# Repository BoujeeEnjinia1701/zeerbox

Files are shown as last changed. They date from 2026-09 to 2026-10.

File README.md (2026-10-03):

# ZeerBox

     

**Area:** Agriculture · **TRL:** 3 of 9 (proof of concept on paper) · **Prototype budget:** $300 USD for the cooling equipment kit · **Difficulty:** 2 of 5

Walk-in evaporative cooling chamber with a solar fan that forces air through a wetted pad, and a controller that responds to humidity.

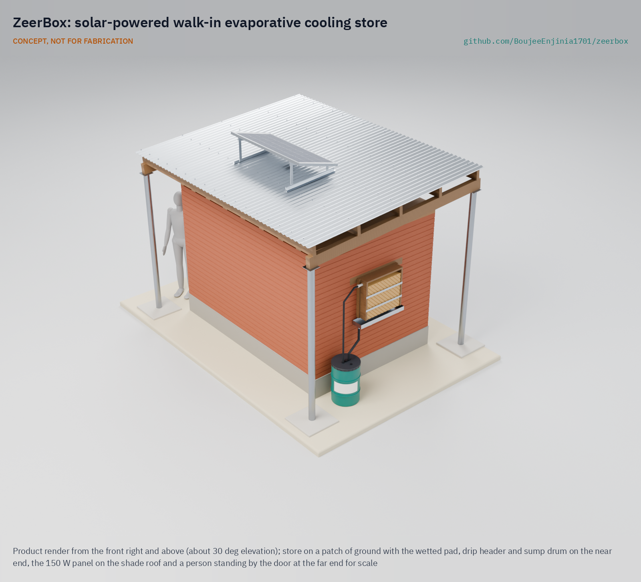
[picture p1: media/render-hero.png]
ZeerBox: solar-powered walk-in evaporative cooling store, product render


[Exploded render](media/render-exploded.png) · [Detail render](media/render-detail.png) · [Interactive 3D model](media/viewer.html) · [Concept blueprint (PDF)](media/concept-blueprint.pdf) · [General arrangement ZBX-DWG-001 (PDF)](cad/drawings/ZBX-DWG-001.pdf) · [Sizing note ZBX-CAL-001](docs/04-calcs/01-sizing.md) · [Prototype build plan](docs/05-build-plan.md) · [Design decisions](docs/06-design-decisions.md) · [Review note](docs/REVIEW.md)

## Concept rationale

Refrigeration is the right answer for a market hub with a business behind it, but it is the wrong starting point for a farm with no grid and no capital. Evaporative cooling needs only water, air and a little power, and in hot, dry weather it can hold produce several kelvin below the outside air (about 10 K on paper for ZeerBox). ZeerBox takes the principle of the clay zeer and the brick zero energy cool chamber and scales it to a room a person can walk into, with shelves at working height, a pad and two 12 V fans for a controlled airflow, and a controller that stops the store from making things worse when the air turns humid.

It is open and garage-buildable because the people who need it are far from any supplier of cold rooms. The structure is ordinary masonry, timber and corrugated sheet that a local mason and carpenter already know, and the cooling kit is a poultry-house pad, generic DC fans, a small pump and solar home system parts, all replaceable from a regional town. Publishing the geometry, calculations and bill of materials lets a partner adapt the size, wall material and crop mix to its own site.

## Burning platform

About 14 % of the food produced for human consumption is lost between harvest and retail, and a further 17 % is wasted. UNEP and FAO estimate that the lack of effective refrigeration alone caused the loss of 12 % of total food production in 2017, enough to feed around 1 billion people at a time when 811 million were hungry ([UNEP and FAO, *Sustainable Food Cold Chains*, 2022](https://www.unep.org/resources/report/sustainable-food-cold-chains-opportunities-challenges-and-way-forward)).

The losses fall hardest on perishables and on the farmers who grow them. Without a cool place to hold a harvest for a few days, a grower must sell on the day of picking at whatever price is offered. A solar walk-in cold room in the Malawi and Zimbabwe pilots cost about $40,000 per unit ([Efficiency for Access](https://efficiencyforaccess.org/wp-content/uploads/Lessons-learned-from-implementing-solar-powered-walk-in-cold-rooms-for-smallholder-agriculture-in-Zimbabwe-and-Mal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)), far beyond a smallholder or a small farmer group.

## Where it could be used

### By industry

| Industry | Use |
| --- | --- |
| Smallholder horticulture | Hold one to five days of tomatoes, peppers, okra and leafy greens so they can be sold when the price is right |
| Farmer groups and cooperatives | Shared store at a collection point, loaded by several members on a rota |
| Market trading | Keep stock fresh between market days at a stall or small depot |
| Agricultural extension and NGOs | Demonstration store and training unit for postharvest handling programs |
| School and community gardens | Short-term storage of garden produce for school meals or local sale |

### By country or region

| Country or region | Why it matters there |
| --- | --- |
| Mali and the wider Sahel | Long hot, dry seasons suit evaporative cooling; in field use in Mali, brick chambers cut the daily peak temperature by up to 10.4 °C when the air was below 40 % RH, but by only 4.2 °C above 70 % RH ([Verploegen, Sanogo and Chagomoka, MIT D-Lab](https://d-lab.mit.edu/sites/default/files/inline-files/GHTC%20-%20Evaluation%20of%20Low-Cost%20Evaporative%20Cooling%20Technologies%20for%20Improved%20Vegetable%20St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); [MIT News, 2018](https://news.mit.edu/2018/mit-d-lab-cite-evaluation-low-cost-evaporative-cooling-devices-mali-0620)) |
| Northern Nigeria | Home of the modern zeer revival ([*TIME*, 2001](https://content.time.com/time/specials/packages/article/0,28804,1936165_1936254_1936632,00.html)); pay-per-crate solar walk-in cold rooms such as ColdHubs, at about $0.50 per crate per day, sit in markets, collection centers and farm clusters rather than on individual farms ([ColdHubs](https://coldhubs.com/); [IFPRI](https://www.ifpri.org/blog/coldhubs-addressing-crucial-problem-food-loss-nigeria-solar-powered-refrigeration/)) |
| India | The zero energy cool chamber was developed at the Indian Agricultural Research Institute; one study found tomato shelf life rising from 6 to 11 days ([*e-planet* 18(2)](https://www.e-planet.co.in/images/Publication/vol-18-2/storage.pdf)) |
| Kenya | MIT D-Lab has piloted forced-air evaporative chambers, some solar powered, the closest prior work to ZeerBox ([MIT D-Lab](https://d-lab.mit.edu/research/evaporative-cooling-vegetable-preservation)) |
| Malawi and Zimbabwe | Solar cold room pilots showed the demand and the cost, about $40,000 per unit, with some rooms largely unused ([Efficiency for Access](https://efficiencyforaccess.org/wp-content/uploads/Lessons-learned-from-implementing-solar-powered-walk-in-cold-rooms-for-smallholder-agriculture-in-Zimbabwe-and-Mal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)) |
| Australia (arid interior) | A high-income example with a long evaporative tradition: the Coolgardie safe, invented in the Western Australian goldfields in the late 1890s, kept food cool by trickling water through a hessian cover ([Western Australian Museum](https://visitwanderland.com.au/explore/golden-outback/warden-finnertys-residence/coolgardie-safe)) |

## What sparked the idea

The idea traces back to the pot-in-pot cooler, or zeer, that Mohammed Bah Abba popularized in Nigeria from 1995: a small earthenware pot inside a larger one, with moist sand between them, cooling the inner pot as the water evaporates ([MIT D-Lab, evaluation of evaporative cooling in Mali](https://d-lab.mit.edu/sites/default/files/inline-files/GHTC%20-%20Evaluation%20of%20Low-Cost%20Evaporative%20Cooling%20Technologies%20for%20Improved%20Vegetable%20St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)). Bah Abba, a teacher from a potmaking family, received a Rolex Award for Enterprise for the work; *TIME* reported that eggplants kept for 27 days instead of three and that 12,000 coolers had been sold ([*TIME*, Best Inventions of 2001](https://content.time.com/time/specials/packages/article/0,28804,1936165_1936254_1936632,00.html)). The zeer shows how far evaporation can go with no power at all, and also where it stops: a pot holds a family's vegetables, not a farmer's harvest, and it cannot tell when the air is too humid to cool. ZeerBox keeps the principle and the name and asks what the same idea looks like at the scale of a walk-in room, with a fan, a deeper pad and a sensor to decide when to use them.

## Problem

Smallholders lose produce after harvest because they have no cold storage. Refrigerated cold rooms cost tens of thousands of dollars, and passive evaporative coolers are small and fail in humid weather. Design with, not for: requirements must come from co-design sessions and field trials with the intended users through a local partner.

## Concept

A walk-in store (2.4 x 1.5 x 2.0 m inside, 24 crates) with double brick walls around a dry rice husk cavity. Two 12 V fans pull outside air through a 150 mm wetted cellulose pad, and a controller reads temperature and humidity inside and out to choose between evaporative cooling, night ventilation and hold. A 150 W solar panel with a small battery powers it. The TRL 3 calculation puts the store at about 24.3 °C on a 35 °C, 30 % RH day, 10.7 K below the outside air, using about 36 L of water. Store humidity is about 81 %, just above the 80 % target and at risk in the unfavorable case (estimates, [ZBX-CAL-001](docs/04-calcs/01-sizing.md)).

Full design precis: [docs/02-concept.md](docs/02-concept.md)

## Key components

- Double brick walls with a dry rice husk cavity, insulated ceiling and shade roof
- 150 mm cellulose evaporative pad with drip header and gutter
- Two 250 mm 12 V DC exhaust fans in a ceiling fan box at the door end
- 60 L sump drum with a 12 V pump
- 150 W PV panel, 20 A PWM charge controller and small LiFePO4 battery
- Controller with inside and outside humidity and temperature sensors

The priced bill of materials is in [bom/bom.csv](bom/bom.csv). Value-engineering target: USD 300 for the cooling equipment kit. Estimated cost of the constructable design: USD 299 for the kit (USD 1 under the target); the structure is built from local materials and costed separately, about USD 574 (indicative).

## Building the prototype

The prototype build plan ([ZBX-BLD-001](docs/05-build-plan.md)) shows how to build the first store, component by component and step by step, with a making sketch for each of the 18 made components and a picture for every one of the 26 assembly steps. Making the concept buildable added a strip footing, lintels and lined openings, a framed ceiling and roof, and moved the two fans from the front wall into a ceiling fan box (decision record ZBX-DDR-003, accepted by Amish on 2026-10-02). A local mason and carpenter can build it; the cooling kit is bought and fitted. The decisions, all made as of 2026-10-02, are kept in the [design decisions register](docs/06-design-decisions.md).

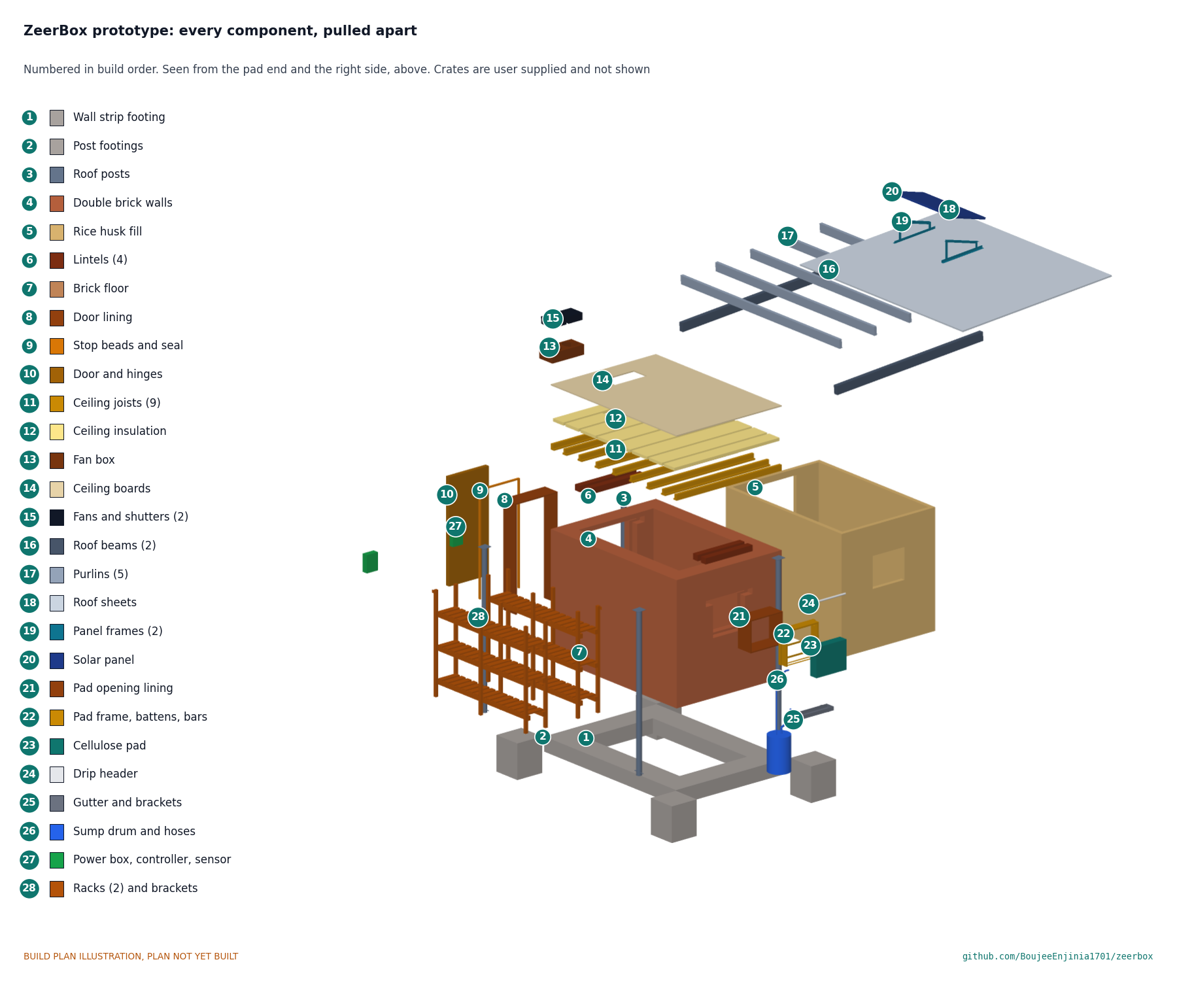
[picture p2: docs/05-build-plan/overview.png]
ZeerBox prototype: every component pulled apart, numbered in build order


## Safety

> A walk-in room: the door must open from inside. Warm recirculating water can grow *Legionella*, so cover, drain and clean the sump weekly. Contains a LiFePO4 battery; use a BMS, fuse it and keep it shaded. Guard the fans. Not for meat, fish, milk or medicines.

## Repository layout

| Folder | Contents |
| --- | --- |
| `docs/` | Problem, concept, requirements, calculations and design decisions |
| `cad/src/` | build123d Python source, the source of truth for all geometry |
| `cad/step/`, `cad/stl/` | Exported models for FreeCAD, other CAD tools and printing |
| `cad/drawings/` | 2D sketches and dimensioned drawings |
| `bom/` | Bill of materials |
| `electronics/` | KiCad schematics and PCB layouts |
| `firmware/` | Microcontroller code |
| `media/` | Renders, perspectives and photos |
| `build-log/` | Dated prototyping notes |

## Documentation

Controlled documents follow the portfolio [documentation standard](.kit/STANDARDS.md). Each carries a document ID (ZBX-PRC-001 for the precis), a version and a revision history. Branded PDFs are built with `python .kit/render.py` and attached to GitHub Releases when a document is tagged, for example `ZBX-PRC-001/v1.0`.

## Credits

Designed by Amish Chadha. See [CONTRIBUTORS.md](CONTRIBUTORS.md) for roles. To cite this design, use [CITATION.cff](CITATION.cff) (GitHub shows it as "Cite this repository").

AI assistance (Claude) was used to accelerate concept renders, prototype documentation and first-pass sizing calculations. Design direction and all decisions are Amish Chadha's, recorded in this repository's decision records (`docs/decisions/`).

## Licenses

- **Hardware** (CAD, drawings, BOM, electronics): [CERN-OHL-S v2](LICENSE)
- **Software** (firmware, scripts, notebooks): [MIT](LICENSE-SOFTWARE)

A project of the [Design Molecule](https://designmolecule.com) lab.

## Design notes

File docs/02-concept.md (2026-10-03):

---
doc_id: ZBX-PRC-001
title: ZeerBox design precis
project: ZeerBox
doc_type: Design precis
version: "0.7"
status: Draft
date: '2026-10-02'
author: Amish Chadha
license: CERN-OHL-S-2.0
revisions:
- version: "0.1"
  date: '2026-09-24'
  author: Amish Chadha
  change: Initial scaffold
- version: "0.2"
  date: '2026-09-25'
  author: Amish Chadha
  change: Populate to TRL 2 (architecture, control modes, first-order numbers, cost, safety, media)
- version: "0.3"
  date: '2026-09-25'
  author: Amish Chadha
  change: TRL 3; record the decisions in ZBX-DDR-001, replace the estimates with ZBX-CAL-001 figures (airflow, heat load, humidity, water, energy, cost), 150 W panel and 20 A charge controller, parametric model and drawing ZBX-DWG-001
- version: "0.4"
  date: '2026-09-25'
  author: Amish Chadha
  change: Recommendations accepted by Amish (DDR-002). 150 mm pad, dry rice husk cavity fill, R3 at 80 % with covered or lined crates; figures from ZBX-CAL-001 v0.2; drawing ZBX-DWG-001 Rev P2
- version: "0.5"
  date: '2026-10-02'
  author: Amish Chadha
  change: "Design made constructable (ZBX-DDR-003): fans in a ceiling fan box, footings, lintels, linings, framed ceiling and roof; cost against the value-engineering target; build plan ZBX-BLD-001 and register ZBX-DEC-001; drawing Rev P3"
- version: "0.6"
  date: '2026-10-02'
  author: Amish Chadha
  change: Design for construction, wall material and partner recorded from Amish's decisions of 2026-10-02 (ZBX-DEC-001)
- version: "0.7"
  date: '2026-10-02'
  author: Amish Chadha
  change: Controller parts list names the clear-lid box, mode lamp position and plate shield (ZBX-DEC-001, decisions 6 to 8)
---

# ZeerBox design precis

ZeerBox is a walk-in store, 2.4 x 1.5 x 2.0 m inside, with double brick walls around a dry rice husk cavity, a shade roof, a 150 mm cellulose pad in the back wall, and two 12 V exhaust fans in the ceiling at the door end that pull outside air through the pad and along the aisle between two shelving racks. A controller reads temperature and humidity inside and outside and chooses between evaporative cooling, night ventilation and hold, and a 150 W solar panel with a small LiFePO4 battery powers it all. The TRL 3 calculation (ZBX-CAL-001 v0.3) shows that on a 35 °C, 30 % RH day the store holds 480 kg of produce at about 24.3 °C, 10.7 K below the outside air, using about 36 L of water and 372 Wh of solar energy. Store humidity is about 81 %, just above the 80 % target (R3, at risk in the unfavorable case). Value-engineering target: USD 300 for the cooling equipment kit. Estimated cost of the constructable design: USD 299 for the kit (USD 1 under the target); the structure, about USD 574 in local materials, is costed separately. How to build it is in the prototype build plan ([ZBX-BLD-001](05-build-plan.md)).

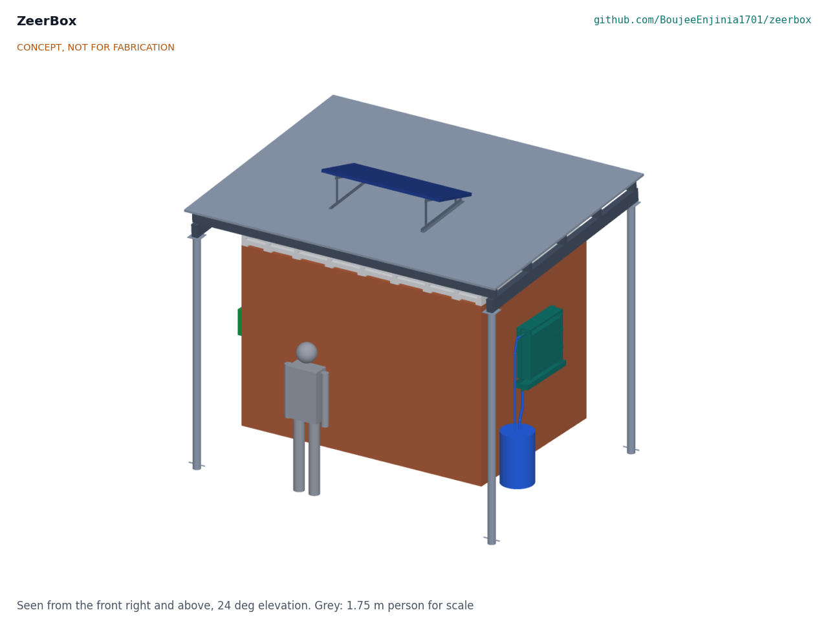
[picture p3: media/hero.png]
Hero render


*Figure 1. ZeerBox from the TRL 3 parametric model, with the pad and sump on the back wall, the 150 W panel on the shade roof and a 1.75 m person for scale. The door is on the far end, with the fan box in the ceiling above it.*

## How it works

1. **Wet.** A 12 V pump in a 60 L sump drum lifts about 3.6 L/min to a perforated header on top of the pad. Water runs down through the 150 mm cellulose pad and drains back to the sump through a gutter. The wall cavity is filled with dry rice husk, which insulates the store and needs no water.
2. **Cool.** Two 250 mm fans in a plywood fan box in the ceiling at the door end exhaust air from the store up into the shaded roof space, which pulls outside air in through the wetted pad on the opposite wall. At the fan and pad operating point of about 563 m³/h, evaporation cools the air from 35 °C toward its wet-bulb temperature of 21.5 °C; with a pad effectiveness of about 88 %, it enters at 23.1 °C and 87 % RH.
3. **Store.** Air sweeps along the 0.6 m aisle and across 24 crates on two three-level timber racks, picking up about 440 W from the walls, ceiling, floor, produce and the day's warm field produce, and leaves through the fans at about 25.5 °C. Leafy and water-sensitive produce goes in covered or lined crates, which hold humidity near the produce.
4. **Decide.** A controller compares the inside and outside readings every minute and runs one of four modes (below). A three-color lamp by the door shows the mode, so users know when to keep the door shut and when the store is not cooling.
5. **Power.** A 150 W panel on the shade roof charges a 12.8 V, 12 Ah LiFePO4 battery through a 20 A PWM charge controller. The battery covers cloud and about 2 h of evening ventilation.

The shade roof sits 450 mm above an insulated ceiling so that sun never falls on the storage room, and its overhang shades the walls for most of the day.

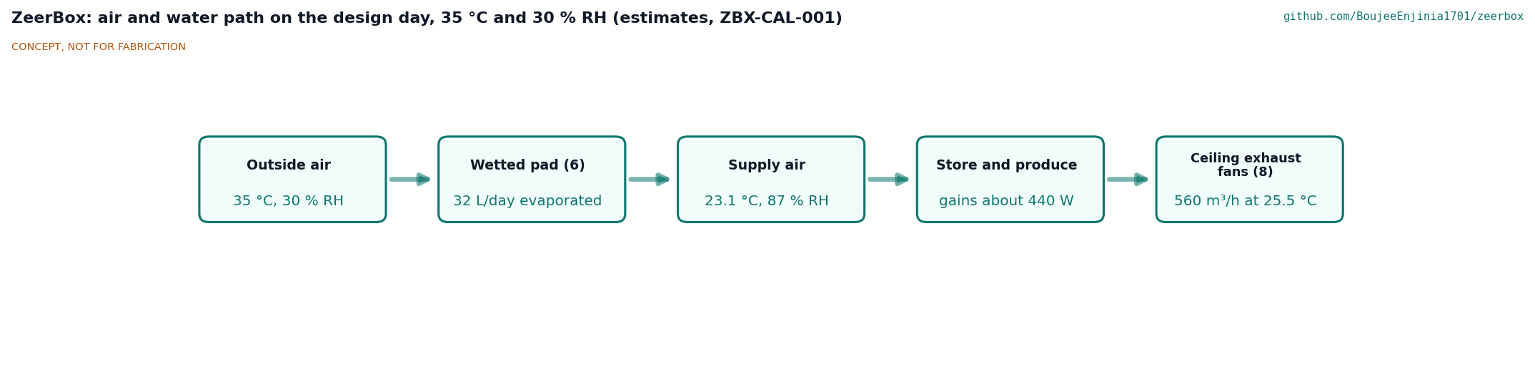
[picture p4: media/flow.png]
Air and water path


*Figure 2. Air and water path on the design day, 35 °C and 30 % RH. Values from ZBX-CAL-001; all are estimates.*

### Control modes

The thresholds are starting values for field tuning (decided by Amish, 2026-09-25, ZBX-DDR-001 item 8).

| Mode | When | Fans | Pump | Lamp |
| --- | --- | --- | --- | --- |
| Evaporative cooling | Outside wet-bulb depression 4 K or more and store above its 20 °C set point | On, speed by store temperature | On, duty cycled to keep the pad wet | Green |
| Night ventilation | Outside air at least 2 K cooler than the store, whatever its humidity | On, at reduced speed after the 2 h evening run | Off | Blue |
| Hold | Outside warmer than the store and too humid to cool | One fan at about 30 % speed, about 8 air changes an hour | Off | Amber |
| Guard | Store RH above 95 % for 60 min, sump float low, or battery low | Low | Off | Red, flashing |

The battery can carry full-speed night ventilation for only about 2.5 h beyond the evening run (ZBX-CAL-001 section 7), so night ventilation runs at reduced speed. The controller logs both sensor pairs and the mode every 10 min to a memory card, so a partner can compare seasons and sites. Firmware is out of scope at TRL 3 beyond a labeled sketch of this logic.

## Main components

Numbers match the exploded view (Figure 3) and `bom/bom.csv`. Dimensions come from `cad/src/model.py` and drawing ZBX-DWG-001.

| # | Component | Choice | Notes |
| --- | --- | --- | --- |
| 1 | Double brick walls and floor | Two 115 mm fired-brick leaves around a 75 mm cavity, 305 mm total, outside 3,010 x 2,110 mm; brick floor on compacted sand; about 1,980 bricks | Fired brick, decided by Amish 2026-10-02 (ZBX-DEC-001) |
| 2 | Dry rice husk cavity fill | About 1.3 m³ of dry rice husk mixed with hydrated lime, on a damp-proof course, capped with mortar | Decided (ZBX-DDR-002 item 12); dry sand is the fallback |
| 3 | Insulated ceiling | Timber boards with about 50 mm of straw, rice husk or foam and a plastic vapor sheet | Keeps roof heat out |
| 4 | Shade roof on posts | Corrugated steel, 3.9 x 3.0 m, on four 90 mm posts in 500 x 500 x 600 mm concrete footings, 450 mm clear above the ceiling | Carries the solar panel; 500 mm footings kept as a minimum (ZBX-DDR-002 item 13) |
| 5 | Insulated door with seal | 0.8 x 1.8 m, timber frame, plywood skins, 50 mm insulation, rubber seal, inside release | Opens from inside without a key |
| 6 | Cellulose pad, frame, header and gutter | 150 mm pad, 0.6 x 0.5 m (0.3 m²), center 1.25 m above ground, with a drip header and return gutter | Decided (ZBX-DDR-002 item 11; was 100 mm) |
| 7 | Sump drum, pump and hoses | 60 L covered drum, 12 V submersible pump about 6 W at 2 m head, float switch, feed and return hoses | Drained and cleaned weekly |
| 8 | Exhaust fans (pair) | Two 250 mm 12 V DC axial fans with guards and gravity shutters, in a ceiling fan box at the door end, blowing up into the roof space (ZBX-DDR-003) | About 12 W and about 280 m³/h each in service |
| 9 | Controller and sensors | Low-cost microcontroller, two digital temperature and RH sensors (inside, outside in a six-plate shield), MOSFET drivers, memory card, mode lamp on top of the box, clear-lid IP65 box | Generic parts |
| 10 | Solar panel | 150 W monocrystalline, about 1,480 x 670 mm, on the shade roof | Decided (item 2) |
| 11 | Power box | 20 A PWM charge controller, 12.8 V 12 Ah LiFePO4 battery with BMS, 15 A fuse, in a ventilated box | Battery decided (item 3); outside the store, shaded |
| 12 | Shelving racks | Two timber racks, 2.2 m long and 0.45 m deep, shelves at 0.30, 0.85 and 1.40 m above the floor | Termite-treated timber or steel angle |
| 13 | Produce crates | 24 ventilated crates, about 500 x 350 x 300 mm, 20 kg each | User supplied; not in the cost |

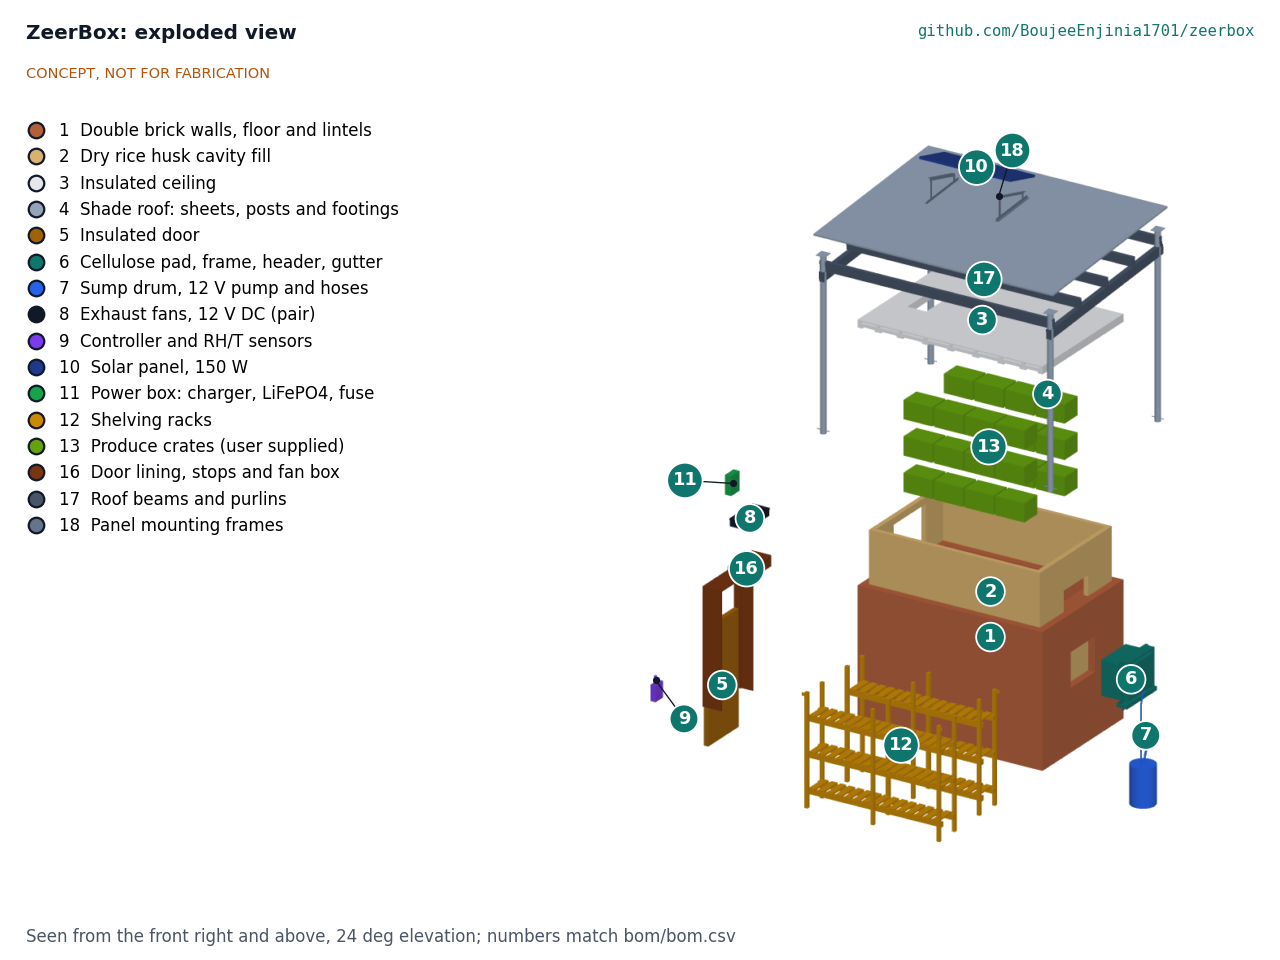
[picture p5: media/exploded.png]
Exploded view


*Figure 3. Exploded view with numbered callouts matching the BOM. The racks are drawn out in front; the crates, ceiling, roof and panel are lifted.*

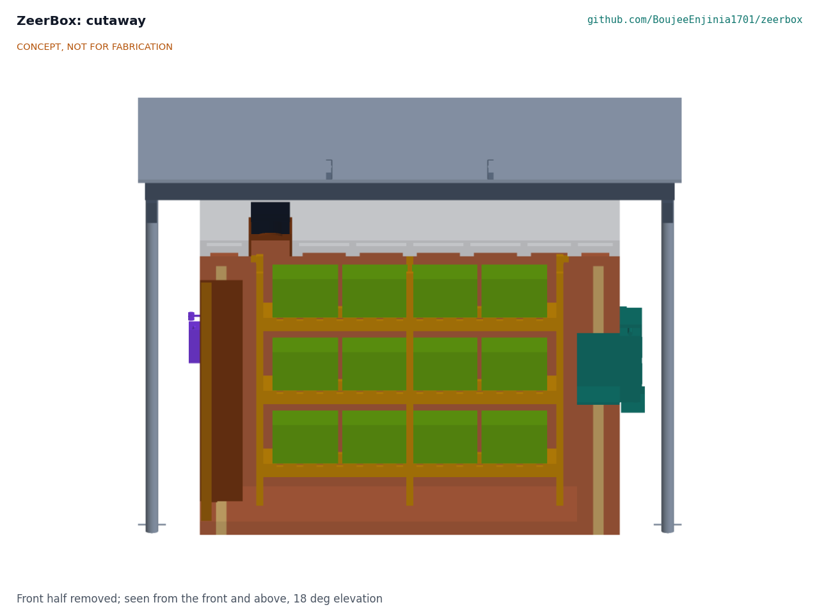
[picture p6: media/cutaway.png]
Cutaway


*Figure 4. Section along the aisle, looking at one rack. The door and the ceiling fan box are at left, the pad at right, and the dry rice husk cavity shows as the pale band inside each end wall.*

## TRL 3 figures

All values come from ZBX-CAL-001 v0.3 (`python docs/04-calcs/sizing.py`). They are first-principles estimates, not measurements. The central case is quoted with the favorable to unfavorable range where it matters.

### Air, pad and store temperature

*Table 1. Design point, 35 °C and 30 % RH.*

| Quantity | Value | Basis |
| --- | --- | --- |
| Outside wet-bulb temperature | 21.5 °C | ASHRAE psychrometric relations |
| Airflow at the fan and pad operating point | 563 m³/h (331 cfm), 18 Pa; about 78 air changes an hour | Two fans on a straight-line curve against the 150 mm pad, shutters and guards |
| Pad face velocity and effectiveness | 0.52 m/s, about 88 % | NTU model calibrated to 75 % at 0.6 m/s for 100 mm, scaled to 150 mm |
| Supply air after the pad | 23.1 °C, 87 % RH | |
| Heat load | 442 W (376 to 558 W) | Walls, ceiling, floor, door, respiration, field heat, leaks |
| Exhaust air | 25.5 °C, 77 % RH | Supply plus 2.35 K |
| Mean store air | 24.3 °C, 81 % RH | |
| **Temperature drop below ambient** | **10.7 K (9.8 to 11.4 K)** | R2 (8 K) met in every case |

This matches field experience: D-Lab measured more than 8 °C of cooling from brick chambers in Mali's dry season. It also shows the limit. The store runs at about 24 °C, well above the 12.5 to 15 °C that tomatoes prefer, so ZeerBox slows spoilage rather than stopping it.

### Humidity

The store averages about 81 % RH while cooling (77 to 85 %), against 80 % in R3, relaxed from 85 % by ZBX-DDR-002. The supply air leaves the 150 mm pad at 87 % RH and loses about 4 to 5 percentage points of RH for every kelvin it warms in the store, so R3 is at risk in the unfavorable case. Reaching 85 % would need a pad about 185 mm deep or more. Covered or lined crates for leafy and water-sensitive produce hold humidity near the produce; they are an operating practice, not a kit item.

### Walls

The decided dry rice husk fill lets in about 84 W through the walls with no water. With the 150 mm pad, a wet sand cavity would let in about 163 W and use about 12 L of water a day, and dry sand (the fallback if no durable, pest-proof husk supply exists) about 192 W. The husk sits on a damp-proof course, is mixed with hydrated lime against insects and is capped with mortar, so it stays dry and closed to rodents.

### Water

| Quantity | Value | Requirement |
| --- | --- | --- |
| Evaporated at the pad | 32 L/day (29 to 35 L) | |
| Wall cavity | none (dry fill) | |
| Bleed, splash and cleaning | 4 L/day | |
| **Total** | **about 36 L/day** | R8 (70 L) met; the 60 L sump covers the 36 L of pad and bleed water |

### Energy

| Quantity | Value | Requirement |
| --- | --- | --- |
| Load while cooling | 31 W (fans 24 W, pump 6 W, controller 1 W) | |
| Daily energy | 372 Wh (fans 288, pump 60, controller 24) | |
| Panel yield, 150 W | 525 Wh/day at 5 peak sun hours and 30 % losses | R7 met, 41 % margin |
| Battery | 154 Wh, 123 Wh usable; 62 Wh needed after sunset | |
| Charge controller | 20 A PWM (1.25 x 9 A Isc) | 10 A was too small |

### Humid weather

| Outside air | Wet-bulb depression | Supply air | Mean store | Drop | Mode |
| --- | --- | --- | --- | --- | --- |
| 35 °C, 30 % RH (design point) | 13.5 K | 23.1 °C | 24.3 °C | 10.7 K | Evaporative cooling |
| 38 °C, 15 % RH | 18.8 K | 21.4 °C | 22.8 °C | 15.2 K | Evaporative cooling |
| 32 °C, 50 % RH | 8.3 K | 24.6 °C | 25.6 °C | 6.4 K | Evaporative cooling |
| 30 °C, 75 % RH | 3.7 K | 26.7 °C | 27.5 °C | 2.5 K | Hold by day, night ventilation |

In the rainy season ZeerBox does little more than a shaded, ventilated shed. The controller's job then is to avoid making things worse: no wet pad adding humidity to a damp room, and cool night air let in whenever it is available.

### Cost

| Group | Indicative cost | Requirement |
| --- | --- | --- |
| Cooling equipment kit (items 6 to 11, 14 and 18) | about $299 | R12: USD 1 under the USD 300 value-engineering target |
| Structure (items 1 to 5, 12, 15, 16 and 17), materials only, costed separately | about $574 | |
| Store total, crates excluded | about $873 | |
| Crates (item 13, user supplied) | about $96 if bought | Not in the total |

Labor for the mason and carpenter is not included.

## Key design choices

Items marked "decided" were decided by Amish on 2026-09-25 (go with recommendation, ZBX-DDR-001 and ZBX-DDR-002) or on 2026-10-02 (ZBX-DEC-001).

- **Forced air through a pad, not a passive chamber (decided).** A fan and pad give a larger, walk-in store with shelves at working height and a controlled airflow; a passive ZECC is cheaper and needs no power but holds far less and cannot respond to humidity.
- **Exhaust fans, pad on the opposite wall (decided).** Pulling air through the pad spreads it evenly over the pad face and keeps the fan motors out of the humid supply air.
- **Dry rice husk cavity fill (decided).** Replaces the wet sand cavity borrowed from the ZECC, which ZBX-CAL-001 found worth little. Decided by Amish, 2026-09-25: go with recommendation (ZBX-DDR-002 item 12), subject to a durable, pest-proof husk supply locally; dry sand is the fallback.
- **Size (decided).** 2.4 x 1.5 x 2.0 m inside for 24 crates, kept until the partner confirms the need.
- **Panel size (decided).** 150 W, with a 20 A charge controller.
- **Battery (decided).** A small LiFePO4 battery for evening ventilation and cloud.
- **Set point and thresholds (decided).** 20 °C set point, 4 K wet-bulb depression threshold and 95 % RH guard as starting values for field tuning.
- **Budget (decided).** `budget_usd: 300` covers the cooling equipment kit; the structure is costed separately. Since 2026-10-01 it is a hypothetical value-engineering target, not a limit.
- **Design for construction (accepted by Amish, 2026-10-02).** Footings, lintels, linings, a framed ceiling and roof, and the fans moved from the front wall to a ceiling fan box, so that every part can be built (ZBX-DDR-003). Decisions are recorded in the register ZBX-DEC-001.
- **Wall material (decided).** Fired brick, as modelled and calculated: the pad wall is kept wet and fired brick does not soften (decided by Amish, 2026-10-02, ZBX-DEC-001).
- **Pad depth and R3 (decided).** A 150 mm pad, R3 relaxed to 80 %, and covered or lined crates for sensitive produce (ZBX-DDR-002 item 11).
- **Roof footings (decided).** 500 x 500 x 600 mm footings as a minimum; the local design wind speed is confirmed with a builder at the chosen site (ZBX-DDR-002 item 13).

## Safety

> **Safety:** ZeerBox is a walk-in room that people enter, with a lithium iron phosphate battery, spinning fans, standing warm water, heavy masonry and a roof that can catch the wind. Treat each of these as a hazard at every stage.

- **Entrapment and air quality.** The door must open from inside at all times, with no outside lock that can be closed on a person inside. Produce respires and uses oxygen; with the fans off and door shut for a long time, open the door and let the store air out before entering.
- **Water-borne bacteria.** Warm recirculating water in pads and sumps can grow *Legionella* and other bacteria, and the fine droplets from a pad can carry them. Cover the sump, drain and clean it weekly, dry the pad out regularly, never use the sump water for drinking or washing produce, and replace a pad that smells or grows slime. Covered water also stops mosquitoes breeding.
- **Mold and spoilage.** A damp, poorly ventilated store can spread mold between crates. The guard mode, weekly cleaning and removal of rotten produce are part of operation.
- **Battery.** A 154 Wh LiFePO4 battery is far less prone to thermal runaway than other lithium chemistries but can still overheat or short. Use a battery with a BMS rated for at least 10 A of charge, fuse it at the terminal, keep it shaded and ventilated outside the store, and do not charge it below 0 °C or above 45 °C.
- **Electrical.** All wiring is 12 V DC and below the touch-safety threshold, but water and wiring meet at the pad and pump. Use IP65 connections, drip loops and a fused supply. Size the charge controller for 1.25 times the panel's short-circuit current.
- **Moving parts.** Fans need guards on both faces. Isolate power before cleaning a fan or the pump.
- **Structure.** Masonry walls (about 7 t of brick) and a roof that people stand under must be built by a competent mason. At a 30 m/s gust each roof post sees about 1.9 kN of uplift after the roof's own weight; set the posts in footings of at least 500 x 500 x 600 mm with an anchor bar through each post foot, tie every purlin to its beam, screw the sheets down, confirm the local design wind speed, and inspect for cracks each season.
- **Rice husk fill.** Dry husk is combustible. Keep the cavity capped with mortar, keep flames and hot work away from the walls during building, and keep the solar wiring in conduit where it passes the wall top.
- **Food safety.** Cooling slows spoilage; it does not make produce safe to eat. ZeerBox is not for meat, fish, milk or medicines.

## Open questions

- Confirm a durable, pest-proof rice husk supply near the chosen site, or fall back to dry sand (ZBX-DDR-002 item 12).
- Confirm the local design wind speed with a builder (ZBX-DDR-002 item 13).
- Confirm pad effectiveness and pressure drop, and the fan curve, from supplier data for the chosen parts.
- Review MIT D-Lab's forced-air evaporative chamber work in Kenya in detail and contact the team.
- Approach the first candidate partner, MIT D-Lab's evaporative cooling team, for a site in Mali's dry-season vegetable areas (decided by Amish, 2026-10-02, ZBX-DEC-001).
- The decisions and the items to confirm are kept in the design decisions register, ZBX-DEC-001 ([docs/06-design-decisions.md](06-design-decisions.md)).

Concept media: [blueprint sheet](../media/concept-blueprint.pdf), [interactive 3D model](../media/viewer.html). General arrangement: `cad/drawings/ZBX-DWG-001.pdf`.

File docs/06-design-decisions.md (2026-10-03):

---
doc_id: ZBX-DEC-001
title: ZeerBox design decisions register
project: ZeerBox
doc_type: Design decisions register
version: "0.2"
status: Draft
date: '2026-10-02'
author: Amish Chadha
license: CERN-OHL-S-2.0
revisions:
  - version: "0.1"
    date: '2026-10-02'
    author: Amish Chadha
    change: Register opened with the build plan; budget treated as a value-engineering target
  - version: "0.2"
    date: '2026-10-02'
    author: Amish Chadha
    change: Amish approved the recommendations for open items 1 to 10 on 2026-10-02 (ZBX-DDR-003 accepted with A1 and A2, fired brick, MIT D-Lab and Mali as first candidates, appearance items); moved to decisions made
---

# ZeerBox design decisions register

Every design decision still to be made, and every decision made, in one place. Each decision is argued in full in its decision record under `docs/decisions/` or in the review note; this register is the index Amish works from. The build plan (`docs/05-build-plan.md`) describes the design as it stands and does not list open decisions.

## Open decisions

None. All open decisions were decided on 2026-10-02.

## To confirm when parts are bought

| # | What to confirm | Why it matters | Source |
| --- | --- | --- | --- |
| 1 | The fan frame is no wider than 290 mm and fits a 250 mm hole | The fan box bay is 310 mm between joists | ZBX-DDR-003, C1 |
| 2 | The fan curve and the pad's pressure drop and effectiveness from supplier data | The airflow of about 560 m³/h and the 10.7 K drop rest on assumed curves | ZBX-CAL-001, sections 1 and 3 |
| 3 | The panel frame has mounting holes on its back flange that the top rails can reach | The panel bolts to the mounting frames through them | ZBX-DDR-003, C8 |
| 4 | Hurricane ties are rated 2 kN or more in uplift | Each purlin crossing sees about 1.1 kN at a 30 m/s gust | ZBX-CAL-001, Table 6a |
| 5 | A durable, pest-proof rice husk supply near the site; otherwise dry sand | The fill's insulation and the wall heat gain depend on it | ZBX-DDR-002, item 12 |
| 6 | The local design wind speed, confirmed with a builder | The roof footings and ties are sized for a 30 m/s gust | ZBX-DDR-002, item 13 |
| 7 | The pump gives about 3.6 L/min at 2 m head and has a float switch | The pad must stay wet and the pump must not run dry | ZBX-CAL-001, section 8 |
| 8 | The charge controller is set for 12.8 V lithium iron phosphate and the BMS takes 10 A of charge | Battery safety and life | ZBX-CAL-001, section 7 |

## Value engineering

Value-engineering target: USD 300 for the cooling equipment kit (a hypothetical control target, not a limit). Estimated cost of the constructable design: USD 299 for the kit (USD 1 under the target). The structure is costed separately at USD 574, and the whole store at USD 873, crates excluded. Main cost drivers and savings worth trying:

- The largest kit lines are the 150 W panel (USD 62), the power box with its battery (USD 62), the pad with its frame, header and gutter (USD 50), the two fans (USD 30) and the controller (USD 30).
- Making the design constructable added USD 22 for the two panel mounting frames and USD 10 for the pad frame, lining, bars and brackets, less USD 3 for the roof clamps they replace: the kit rose from USD 270 to USD 299.
- The structure rose from USD 355 to USD 574 because the concept did not price the strip footing (USD 35), the roof beams and purlins (USD 70) or the door lining and fan box (USD 25), and underpriced the framed ceiling and the racks.
- Savings worth trying: galvanized steel angle in place of aluminium for the panel frames (about USD 8 less, needs painting at cut ends); a 100 W panel is not one (6 % short on energy, ZBX-CAL-001 section 7); in the structure, mud brick or stabilized block if decision 4 allows, and racks of local poles in place of sawn timber.

## Decisions made

| Date | Decision | Decided by | Record |
| --- | --- | --- | --- |
| 2026-09-25 | TRL 2 review items 1 to 8: the USD 300 budget covers the cooling kit with the structure costed separately; 150 W panel; keep the battery; forced air through a pad; exhaust fans with the pad opposite; wet sand cavity pending the heat balance; 24 crates; control thresholds as starting values | Amish: "proceed with all of your recommendations across all batches. Make sure we don't proceed to TRL 4 on any of them." | ZBX-DDR-001 |
| 2026-09-25 | Items 11 to 13: 150 mm pad, R3 relaxed to 80 % with covered or lined crates; dry rice husk fill in place of wet sand (dry sand as fallback); 500 x 500 x 600 mm roof footings as a minimum | Amish: "i accept all your recommendations, go with them across all repos." | ZBX-DDR-002 |
| 2026-09-30 | Make the design physically buildable while drawing the build plan | Amish: "If you are realising that the design cannot be built as per concept - fix the design assumptions to match and be physically feasible as you draw the illustrations." | ZBX-DDR-003 (the changes themselves await his review, open decision 1) |
| 2026-09-30 | Open decisions are kept in this register, not in the build plan | Amish: "don't log outstanding decisions in this build plan - that is not the place for it. that should be in a separate design document logged and named as such" | This register |
| 2026-10-01 | `budget_usd` is a value-engineering target, not a spending limit | Amish: "the budgets are a hypothethical control target to ensure we are thinking along a value engineering lens. its ok to ensure wording reflects that the hypothesis budget was x - the real cost being accrued is y" | ZBX-CAL-001 v0.3, section 11 |
| 2026-10-02 | Design for construction accepted: the changes C1 to C10 of ZBX-DDR-003, as made | Amish: "APPROVED: The open decisions from the last wave (TremorTrace to ZeerBox) came in after the review and aren't on the page either." | ZBX-DDR-003, Table 1 |
| 2026-10-02 | Fan position: the two fans stay in the ceiling fan box at the door end, as modelled | Amish: "APPROVED: The open decisions from the last wave (TremorTrace to ZeerBox) came in after the review and aren't on the page either." | ZBX-DDR-003, A1 |
| 2026-10-02 | Exhaust into the roof space accepted, with a check at TRL 4 that moist air does not drift back to the pad; a short duct past the roof edge is added only if it does | Amish: "APPROVED: The open decisions from the last wave (TremorTrace to ZeerBox) came in after the review and aren't on the page either." | ZBX-DDR-003, A2 |
| 2026-10-02 | Wall material: fired brick, as modelled and calculated | Amish: "APPROVED: The open decisions from the last wave (TremorTrace to ZeerBox) came in after the review and aren't on the page either." | ZBX-DDR-001, item 9 |
| 2026-10-02 | First co-design partner, region and crop mix: a group that has already field-tested evaporative cooling chambers with vegetable growers; the first candidate to approach is MIT D-Lab's evaporative cooling team, with a dry-season vegetable area of Mali as the first candidate region and tomatoes, peppers and okra as the crop mix, leafy greens on a separate rack | Amish: "APPROVED: The open decisions from the last wave (TremorTrace to ZeerBox) came in after the review and aren't on the page either." | ZBX-DDR-001, item 10 |
| 2026-10-02 | Clear window in the controller lid only; the power box has a plain door | Amish: "APPROVED: The open decisions from the last wave (TremorTrace to ZeerBox) came in after the review and aren't on the page either." | REVIEW.md, 2026-09-26, item 2 |
| 2026-10-02 | Mode lamp on top of the controller box beside the door, added to the model | Amish: "APPROVED: The open decisions from the last wave (TremorTrace to ZeerBox) came in after the review and aren't on the page either." | REVIEW.md, 2026-09-26, item 3 |
| 2026-10-02 | Outside sensor shield: stacked round plates 46 mm across | Amish: "APPROVED: The open decisions from the last wave (TremorTrace to ZeerBox) came in after the review and aren't on the page either." | REVIEW.md, 2026-09-26, item 4 |
| 2026-10-02 | Plinth render band: an optional 10 mm finish 300 mm high, the mason's choice | Amish: "APPROVED: The open decisions from the last wave (TremorTrace to ZeerBox) came in after the review and aren't on the page either." | REVIEW.md, 2026-09-26, item 5 |
| 2026-10-02 | Hose and conduit routing accepted as sketched in the build plan, routed on site | Amish: "APPROVED: The open decisions from the last wave (TremorTrace to ZeerBox) came in after the review and aren't on the page either." | REVIEW.md, 2026-09-26, item 6 |

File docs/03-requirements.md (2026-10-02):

---
doc_id: ZBX-REQ-001
title: ZeerBox requirements
project: ZeerBox
doc_type: Requirements
version: "0.5"
status: Draft
date: '2026-10-02'
author: Amish Chadha
license: CERN-OHL-S-2.0
revisions:
- version: "0.1"
  date: '2026-09-24'
  author: Amish Chadha
  change: Initial scaffold
- version: "0.2"
  date: '2026-09-25'
  author: Amish Chadha
  change: First measurable requirements for TRL 2, design point and status against the concept
- version: "0.3"
  date: '2026-09-25'
  author: Amish Chadha
  change: Redefine R12 as the cooling equipment kit (ZBX-DDR-001 item 1); R7 on the decided 150 W panel; TRL 3 status from ZBX-CAL-001
- version: "0.4"
  date: '2026-09-25'
  author: Amish Chadha
  change: Recommendations accepted by Amish (DDR-002). R3 relaxed to 80 %; status from ZBX-CAL-001 v0.2 (150 mm pad, dry rice husk fill)
- version: "0.5"
  date: '2026-10-02'
  author: Amish Chadha
  change: Status from ZBX-CAL-001 v0.3 after the design for construction (ZBX-DDR-003); R12 reported against the value-engineering target
---

# ZeerBox requirements

These requirements are checked by calculation in ZBX-CAL-001 v0.3 at TRL 3, after the design was made constructable (ZBX-DDR-003). Seven are met (three of them by design or logic review only), the kit cost (R12) is USD 1 under its value-engineering target, **R3 is at risk**, none is not met, and R6, R10 and R11 cannot be verified at TRL 3. Targets are not yet validated with users and will be revised after co-design sessions (see ZBX-PRB-001).

The **design point** used throughout is outside air at 35 °C and 30 % RH (wet bulb 21.5 °C), a full store of 480 kg of mixed vegetables, and 100 kg of fresh produce loaded per day at 32 °C.

*Table 1. Requirements and TRL 3 status. Values are central estimates from ZBX-CAL-001 v0.3, with the favorable to unfavorable range where it matters.*

| ID | Requirement | Target | Verification | TRL 3 status (ZBX-CAL-001) |
| --- | --- | --- | --- | --- |
| R1 | Storage capacity | 20 or more standard 20 kg crates (400 kg or more) on shelves; one adult can walk in and reach every crate without lifting any crate above 1.6 m | Layout model; later loading trial | Met: 24 crates, 480 kg; top shelf 1.40 m above the floor |
| R2 | Cooling at the design point | Mean store air temperature 8 K or more below outside air | Psychrometric and heat balance calculation; later logged field data | Met: 10.7 K (9.8 to 11.4 K); store 24.3 °C |
| R3 | Humidity for produce | Store RH 80 % or more while cooling, to limit water loss; covered or lined crates for leafy and water-sensitive produce | Calculation; later logged field data | **At risk:** 81 % (77 to 85 %) |
| R4 | Behavior in humid weather | Controller detects outside air too humid to cool (wet-bulb depression under 4 K) and switches to night ventilation or hold, with a visible mode indicator | Controller logic review; later bench test with sensors | Met by logic review: 30 °C and 75 % RH gives 3.7 K and switches to hold |
| R5 | Mold and condensation guard | Pad pump stops if store RH stays above 95 % for 60 min; store air changes at least once per hour whenever produce is inside | Controller logic review | Met by logic review: hold mode gives about 8 air changes an hour at about 2 W |
| R6 | Shelf life | Tomato shelf life at least 1.5 times that of ambient storage in the dry season (for example 6 days to 9 days or more) | Literature comparison; later paired storage trial with the partner | Not verifiable at TRL 3; ZECC data (about 1.8 times) come from a cooler, more humid chamber |
| R7 | Solar operation | Fans, pump and controller run from one PV panel with no grid for a full design day: 10 h of cooling plus 2 h of evening ventilation | Energy balance | Met: 372 Wh needed, 525 Wh from the 150 W panel (41 % margin) |
| R8 | Water use | 70 L or less of water per design day, including pad and wall cavity; sump holds at least one day | Water balance | Met: about 36 L (no cavity water); 60 L sump for 36 L of pad and bleed water |
| R9 | Low-voltage and safe | All electrical parts at 12 V DC nominal, fused at the battery; fans guarded; door opens from inside without a key | Design review | Met by design review |
| R10 | Local build and repair | Walls, roof, door and shelves built by a local mason and carpenter; every fan, pump, sensor and pad replaceable in 30 min or less with generic parts | Design review; parts availability survey with the partner | Not verifiable at TRL 3 |
| R11 | Durability | Structure 10 years or more; pad 3 years or more with cleaning; fans and pump 3 years or more in dust | Material review; supplier data | Not verifiable at TRL 3; roof footings 1.8 times the uplift at 30 m/s, 500 mm kept as a minimum (ZBX-DDR-002); roof beams and purlins sized (ZBX-CAL-001 v0.3) |
| R12 | Affordable | Cooling equipment kit (pad, sump and pump, fans, controller, solar panel, power box, wiring and panel frames: BOM items 6 to 11, 14 and 18) priced against the USD 300 value-engineering target (`project.yaml` budget). The structure (items 1 to 5, 12, 15, 16 and 17) is built from local materials and costed separately | Priced BOM (`bom/bom.csv`) | Value-engineering target: USD 300 for the kit. Estimated cost of the constructable design: USD 299 (USD 1 under the target); structure USD 574, reported separately |

R12 was redefined on 2026-09-25 by Amish's decision to go with the TRL 2 recommendation (ZBX-DDR-001 item 1). Its earlier target, the complete store for $300, was not met at about $575. Since 2026-10-01 the USD 300 figure is a hypothetical value-engineering target, not a limit (Amish: "the budgets are a hypothethical control target to ensure we are thinking along a value engineering lens"), so R12 is reported as over or under the target.

R3 was relaxed from 85 % to 80 % on 2026-09-25 by Amish's decision to go with the TRL 3 recommendation (ZBX-DDR-002, item 11), together with a 150 mm pad and produce-level measures (covered or lined crates). At 85 % R3 would still not be met: the store averages 81 % and 85 % needs a pad about 185 mm deep or more.

## Assumptions

- Direct evaporative pad effectiveness of 75 % for a 100 mm cellulose pad at 0.6 m/s face velocity, scaled for velocity and depth in ZBX-CAL-001; about 88 % for the decided 150 mm pad at 0.52 m/s. Manufacturer data for deeper pads show 90 % or more ([CELdek specification](https://piec.com/celdek/)); 70 to 80 % is assumed for 100 mm.
- The fans are taken as a straight-line curve from 400 m³/h free air to a 50 to 70 Pa shut-off; pad pressure drop is 15 Pa at 1.0 m/s. Both need supplier data.
- The heat load at the design point is 442 W (376 to 558 W), from the heat balance in ZBX-CAL-001 v0.2.
- Dry rice husk in the wall cavity conducts about 0.06 W/(m·K) and is kept dry and pest-free (assumption).
- Dry-season solar resource of about 5 peak sun hours, with 30 % combined losses for heat, dust, PWM charging and wiring.
- Tomato shelf life gains are taken from zero energy cool chamber trials, which run cooler and more humid than a forced-air store; R6 may be optimistic.
- Recommended produce conditions follow the UC Davis Postharvest Center (tomato 12.5 to 15 °C for mature green, 90 to 95 % RH). ZeerBox cannot reach these temperatures in the design case; R2 is set on temperature drop, not absolute temperature.

## Requirements not met or at risk at TRL 3

- **R3 (humidity), at risk:** the 150 mm pad supplies air at 87 % RH, and the store averages 81 % in the central case but 77 % in the unfavorable case, against 80 %. The air loses about 4 to 5 percentage points of RH per kelvin as it warms across the store. Covered or lined crates hold humidity near the produce; field data will show whether they are enough.
- No requirement is not met. R2 moved from at risk to met (10.7 K, 9.8 K unfavorable) with the 150 mm pad and dry rice husk fill (ZBX-DDR-002, items 11 and 12).

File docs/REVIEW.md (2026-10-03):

# Review note: ZeerBox

## Session 2026-09-25: /populate to a strong TRL 2

### What was done

- `docs/01-problem.md` (ZBX-PRB-001 v0.2): problem with cited loss figures, three gaps (cost of refrigeration, small passive coolers, humid-weather failure), users, operating environment, constraints, out of scope, prior work with sources (zeer, ZECC, MIT D-Lab Mali and Kenya, fan and pad practice, solar cold rooms), open questions, and a co-design checklist (none existed before; added in the portfolio's standard form).
- `docs/03-requirements.md` (ZBX-REQ-001 v0.2): 12 measurable requirements (R1 to R12) with a defined design point, a TRL 2 status column and a list of requirements not met.
- `docs/02-concept.md` (ZBX-PRC-001 v0.2): how it works, four control modes, numbered components, psychrometric and heat balance estimates, airflow, water, solar energy, humid-weather performance, cost, design choices, safety and open questions.
- `cad/src/concept_media.py`: massing model of the store (double brick walls and floor, wet sand cavity, insulated ceiling, shade roof on posts, door, pad assembly, sump and pump, fans, controller, solar panel, power box, racks, crates), with a hand-placed 1.75 m person in front of the long wall so no roof post hides the figure.
- `media/`: `hero.png`, `concept-blueprint.png`, `.pdf` and `.svg`, `exploded.png` with callouts 1 to 13, `cutaway.png` along the aisle, `flow.png` (air and water path, estimates), `model.glb` and `viewer.html`.
- `bom/bom.csv`: 14 lines with indicative USD prices, numbered to match the exploded view (item 14, wiring and plumbing, has no callout). `bom/bom-notes.md` gives the structure and equipment subtotals.
- `README.md`: hero image and links line before "## Problem"; problem, concept and key components brought in line with the precis; short safety section added.
- `docs/pdf/`: branded PDFs of the three controlled documents.
- `project.yaml` is unchanged. Its pitch and problem remain accurate.

### Key results (estimates, to be checked at TRL 3)

| Quantity | Estimate | Requirement |
| --- | --- | --- |
| Store size and capacity | 2.4 x 1.5 x 2.0 m inside; 24 crates, about 480 kg | R1 met |
| Supply air at 35 °C, 30 % RH | about 24.9 °C, 74 % RH (75 % pad effectiveness) | |
| Mean store temperature | about 26 °C, about 9 K below ambient | R2 met |
| Store RH | about 65 to 75 % | **R3 not met** (85 %) |
| Heat gain | about 550 W (walls 250 W, respiration 70 W, field heat 80 W, other 150 W) | |
| Airflow | about 650 m³/h (380 cfm), 0.6 m/s at the pad, about 90 air changes per hour | |
| Water | about 55 L/day (31 L pad, 20 L cavity, 4 L bleed) | R8 met |
| Electrical load | about 31 W cooling; about 350 Wh/day | |
| Solar yield, 100 W panel | about 350 Wh/day | **R7 at risk, no margin** |
| Humid season, 30 °C and 75 % RH | about 1.5 K of cooling | R4 handled by mode change |
| Parts cost, crates excluded | about $575 (structure about $340, equipment kit about $233) | **R12 not met, about 90 % over $300** |

Requirements not met or at risk:

- **R3 (store RH 85 %) not met:** forced air warms by about 2.6 K across the store and its RH falls to about 65 to 75 %.
- **R7 (solar) at risk:** the 100 W panel just matches the design-day load.
- **R12 (cost) not met:** about $575 against $300. The structure alone is over budget.
- **R6 (shelf life), R10 and R11 unverified:** R6 relies on ZECC data from cooler, more humid chambers and may be optimistic.

### Proposed, awaiting Amish

1. **Budget.** Options: (a) redefine the $300 budget as the cooling equipment kit (about $233), with the structure built from local materials and costed separately, as SunSpoke does for its pack; (b) raise `budget_usd` to about $600 for the complete store; (c) shrink the store to about 12 crates to cut the structure cost by about a third, which would still exceed $300. Recommendation: (a), and redefine R12 as "equipment kit $300 or less; structure costed separately". `project.yaml` is unchanged.
2. **Solar panel size.** 100 W (no margin) or 150 W (about $20 more, about 50 % margin). Recommendation: 150 W.
3. **Battery.** Keep a 12.8 V 12 Ah LiFePO4 battery for evening ventilation, or run PV-direct and save about $50. Recommendation: keep it.
4. **Forced air through a pad** rather than a passive ZECC-style chamber. Recommendation: forced air (this is the pitch).
5. **Exhaust fans with the pad on the opposite wall** rather than blowing air in through the pad. Recommendation: exhaust.
6. **Wet sand cavity walls** rather than a single insulated wall. Recommendation: wet cavity, pending a TRL 3 heat balance.
7. **Store size** of 24 crates rather than a smaller single-farm store or a larger group store. Recommendation: keep 24 until a partner confirms the need.
8. **Control thresholds:** 20 °C set point, 4 K wet-bulb depression, 95 % RH guard. Recommendation: use as starting values.
9. **Fired brick** rather than mud brick or block for the walls.
10. **First partner, region and crop mix** for co-design (for example a dry-season vegetable area in the Sahel, or a group already using D-Lab designs in Kenya).

### Safety concerns

- A walk-in room: entrapment and stale air. The door must open from inside with no outside lock that can shut someone in.
- Warm recirculating water in the pad and sump can grow *Legionella* and other bacteria; weekly draining and cleaning, a covered sump and no reuse of sump water are part of the design.
- Mold in a damp store; guard mode and cleaning routine.
- LiFePO4 battery (154 Wh): BMS, terminal fuse, shaded and ventilated box.
- Fans: guards on both faces; isolate before cleaning.
- Masonry and roof: competent mason, roof anchored against uplift, footings protected from the wet cavity.
- The store is not cold chain and must not be used for meat, fish, milk or medicines.

### Problems and notes

- No SwapCell pack is used; the 12 V load of about 31 W does not justify a 48 V pack.
- The legacy `cad/src/model.py` placeholder is untouched (TRL 3 work).
- In the hero view the door and fans face away from the camera; they appear in the exploded view, the cutaway, the blueprint's right view and the 3D viewer.
- In the exploded view the controller (9) and power box (11) are small at this scale and partly hidden by their callouts.
- The co-design checklist in PRB-001 is new in this session (there was none to keep); remove it if Amish prefers.

### Recommended next step

Review this note and the media, then decide items 1 and 2. If approved, run `/advance-trl3` to check the heat balance (including a wet cavity), the pad and fan selection, the RH problem (R3) and the solar sizing by calculation, and to produce the parametric model and drawing sheet.

## Session 2026-09-25: TRL 3

Amish reviewed the TRL 2 points on 2026-09-25 and wrote: "proceed with all of your recommendations across all batches. Make sure we don't proceed to TRL 4 on any of them." This session advanced ZeerBox to TRL 3 and stopped there. **TRL 4 is on hold by Amish's instruction.**

### What was done

- `docs/decisions/0001-trl2-review-decisions.md` (ZBX-DDR-001 v0.1): records items 1 to 8 as decided by Amish, 2026-09-25 (go with recommendation), the cross-cutting approvals, and the open items 9 to 13.
- `docs/04-calcs/01-sizing.md` (ZBX-CAL-001 v0.1) and `docs/04-calcs/sizing.py`: psychrometrics, fan and pad operating point, heat balance with three scenarios, humidity, wet cavity against dry fills, off-design weather, energy and solar, water, electrical, structure (bricks, bearing, roof uplift) and cost, with a results table for R1 to R12. The script reads `cad/src/model.py`, `bom/bom.csv` and `project.yaml`, prints every quoted number and writes `docs/04-calcs/results.csv`.
- `cad/src/model.py`: parametric build123d model (all 13 modeled BOM lines) with `PARAMS` and `derived()`; exports `cad/step/zeerbox-assembly.step`, `zeerbox-structure.step`, `zeerbox-cooling-kit.step` and matching STL files.
- `cad/src/sheets.py` and `cad/drawings/ZBX-DWG-001.svg`, `.pdf`, `.png`: general arrangement at Rev P1, 1:50, third-angle, with key dimensions, marked "CONCEPT, NOT FOR FABRICATION" and "PRELIMINARY, NOT FOR FABRICATION". The concept sheet keeps ZBX-DWG-010, so DWG-001 was the next free number.
- `bom/bom.csv` and `bom/bom-notes.md`: every line priced with a supplier type; 150 W panel, 20 A PWM controller, 2.5 mm² PV cable, 500 mm post footings, brick and sand quantities from the calculation.
- `cad/src/concept_media.py` now builds from the model; `media/` refreshed (hero, blueprint, exploded, cutaway, flow, `model.glb`, `viewer.html`). All images were inspected; temporary `media/_views*` folders were deleted.
- ZBX-PRB-001, ZBX-PRC-001 and ZBX-REQ-001 raised to v0.3 with the decisions and the checked figures; R12 redefined as the cooling equipment kit. `README.md` updated (TRL 3, 150 W, costs, links). `project.yaml`: `trl: 3`, `trl_target: 3`, evidence list extended. The pitch and problem lines are unchanged (no rewording was recommended).
- PDFs of all controlled documents rebuilt in `docs/pdf/`.

### Requirements (ZBX-CAL-001), not met first

| ID | Status | Value (central, range) |
| --- | --- | --- |
| R3 | **Not met** | Store RH 71 % (66 to 76 %) against 85 % |
| R2 | **At risk** | 9.1 K below ambient (8.0 to 10.0 K); store 25.9 °C |
| R6, R10, R11 | Not verifiable at TRL 3 | Shelf life, local repair times and component life need field data or a partner |
| R1, R7, R8, R12 | Met | 24 crates, top shelf 1.40 m; 372 Wh/day against 525 Wh (41 % margin); 44 L/day; kit $260 against $300 |
| R4, R5, R9 | Met by logic or design review | Mode switch at 3.7 K depression; about 8 air changes an hour in hold; 12 V, fused, guarded, inside release |

Key numbers: airflow 584 m³/h at 16 Pa (not 650 m³/h); heat load 418 W (not 550 W); supply air 24.8 °C and 75 % RH; about 44 L of water per day (not 55 L); 372 Wh/day (the 100 W panel of TRL 2 would have been 6 % short); structure about $360 and store total about $620, crates excluded.

Other findings: the 10 A charge controller was too small for a 150 W panel (1.25 x Isc is 11.2 A), so the BOM now has 20 A; and the wet sand cavity is worth only about 0.15 K over dry sand in the central case and is slightly worse than dry sand in the unfavorable case.

### Decisions recorded

Decided by Amish, 2026-09-25, go with recommendation (ZBX-DDR-001): (1) keep `budget_usd: 300` for the cooling equipment kit, structure costed separately, R12 redefined; (2) 150 W panel; (3) keep the battery; (4) forced air through a pad; (5) exhaust fans with the pad opposite; (6) wet sand cavity walls, pending the TRL 3 heat balance; (7) 24 crates; (8) control thresholds as starting values. Cross-cutting: SwapCell interface v0.3 and shared-pack pricing do not apply (no SwapCell pack); partners are picked per area later.

### Still awaiting Amish

9. Wall material: fired brick, mud brick or block. No recommendation was stated; fired brick is the working choice.
10. First partner, region and crop mix (left open by the per-area partner rule).
11. R3 not met and R2 at risk. **Decided by Amish, 2026-09-25: go with recommendation (ZBX-DDR-002).** Options: 150 mm pad (10.5 K, 81 % RH, about $10 more), a relaxed R3, produce-level measures. Recommendation: a 150 mm pad and R3 at 80 %.
12. Wet cavity against a dry insulating fill. **Decided by Amish, 2026-09-25: go with recommendation (ZBX-DDR-002).** Dry rice husk gives 9.2 K (8.2 K unfavorable) with no cavity water. Recommendation: dry fill, if a durable, pest-proof fill is available locally. This reopens the substance of decided item 6, because the heat balance it was waiting for does not support it.
13. Roof footings and design wind speed: **Decided by Amish, 2026-09-25: go with recommendation (ZBX-DDR-002).** 500 x 500 x 600 mm footings are in the model; confirm the local design wind speed.

### Safety concerns

- Roof uplift is the main structural hazard: about 2.2 kN per post at a 30 m/s gust. The footings were enlarged to 500 x 500 x 600 mm; a 400 mm footing would have had no margin.
- Walk-in room: the door opens from inside with no outside lock; air the store out before entering after a long hold.
- *Legionella* and other bacteria in the warm sump and pad: covered sump, weekly drain and clean, no reuse of sump water.
- LiFePO4 battery (154 Wh): BMS rated for at least 10 A of charge, terminal fuse, shaded and ventilated box; charge controller sized to 1.25 x Isc.
- Fans guarded on both faces; isolate before cleaning. Heavy masonry (about 7 t of brick and 2.4 t of wet sand) needs a competent mason, and the wet cavity must not undermine the footings.
- Not cold chain; not for meat, fish, milk or medicines.

### Problems and notes

- No TRL 4 material exists in the repo; none was created. `build-log/` holds only its README. STANDARDS section 9 asks for a build-log entry on a TRL change; none was added because build-log work is outside this brief, so the TRL change is recorded here and in `project.yaml`.
- No citations were flagged as unchecked in the TRL 2 review; no new sources were added.
- Pad pressure drop, pad effectiveness at 0.54 m/s and the fan curve are assumptions; supplier data for the chosen parts should replace them.
- As at TRL 2, the hero view shows the pad end, and the small controller (9) and power box (11) are partly hidden by their callouts in the exploded view.

### Recommended next step

Decide items 11 and 12 (pad depth, the R3 target and the cavity fill), then items 9 and 13. These are paper changes that can be made at TRL 3: update `PARAMS`, rerun `sizing.py`, and reissue the drawing at Rev P2.

TRL 4 is on hold by Amish's instruction. For reference only, TRL 4 would need: a pad and fan test article with measured airflow, pressure drop and pad effectiveness; a bench test of the controller logic with sensors; a lab test report (TST with `environment: lab`); and build-log entries. None of this has been started.

## Session 2026-09-25: recommendations accepted

Amish wrote on 2026-09-25, in chat: "i accept all your recommendations, go with them across all repos." Every open item with a recommendation is now **Decided by Amish, 2026-09-25: go with recommendation**, recorded in `docs/decisions/0002-recommendations-accepted.md` (ZBX-DDR-002 v0.1). The repo stays at TRL 3.

### Decisions applied and what changed

- **Item 11 (R3 not met, R2 at risk):** option (c). Pad 100 to 150 mm (`PAD_T` in `cad/src/model.py`; BOM line 6 $30 to $40); R3 target 85 to 80 %; covered or lined crates for leafy and water-sensitive produce as an operating practice. Pad effectiveness 75.7 to 88.2 %; airflow 584 to 563 m³/h; supply air 24.8 °C and 75 % RH to 23.1 °C and 87 % RH.
- **Item 12 (wet cavity against a dry fill):** option (b). Dry rice husk fill, lime-treated, on a damp-proof course and capped with mortar; dry sand is the fallback if no durable, pest-proof supply exists locally. Supersedes ZBX-DDR-001 item 6. BOM line 2 $20 to $15 (wetting pipe removed); cavity water 12 to 0 L/day; fill mass 2.4 to 0.15 t; wall line load 9.3 to 7.1 kN/m.
- **Item 13 (roof footings):** keep 500 x 500 x 600 mm footings as a minimum and confirm the local design wind speed with a builder at the chosen site. No geometry change.
- Combined result: store 25.9 to 24.3 °C; drop 9.1 K (8.0 to 10.0 K) to 10.7 K (9.8 to 11.4 K); store RH 71 % to 81 % (77 to 85 %); heat load 418 to 442 W; water 44 to 36 L/day; kit $260 to $270; structure $360 to $355; store total $620 to $625.
- **Budget:** `budget_usd` unchanged at $300 for the cooling equipment kit (no budget change was recommended). Pitch and problem lines unchanged (no rewording was recommended).
- Files: `cad/src/model.py` (and STEP, STL re-exported), `docs/04-calcs/sizing.py` and `results.csv`, ZBX-CAL-001 v0.2, ZBX-REQ-001 v0.4, ZBX-PRC-001 v0.4, ZBX-PRB-001 v0.4, ZBX-DDR-001 v0.2, `bom/bom.csv`, `bom/bom-notes.md`, drawing ZBX-DWG-001 at Rev P2 (`cad/src/sheets.py`), `cad/src/concept_media.py` and all of `media/`, `README.md`, `project.yaml` (DDR-002 added to the evidence list). All PDFs in `docs/pdf/` rebuilt; the drawing and media were regenerated so no generated file shows the old site address.
- `README.md` gained "Concept rationale", "Burning platform", "Where it could be used" and "What sparked the idea" (the Bah Abba pot-in-pot cooler, northern Nigeria, 1990s).

### Requirements (ZBX-CAL-001 v0.2), not met first

| ID | Status | Value (central, range) |
| --- | --- | --- |
| (none) | Not met | No requirement is not met |
| R3 | **At risk** | Store RH 81 % (77 to 85 %) against 80 % |
| R6, R10, R11 | Not verifiable at TRL 3 | Shelf life, local repair times and component life need field data or a partner |
| R1, R2, R7, R8, R12 | Met | 24 crates; 10.7 K (9.8 to 11.4 K); 41 % solar margin; 36 L/day; kit $270 against $300 |
| R4, R5, R9 | Met by logic or design review | Mode switch at 3.7 K depression; about 8 air changes an hour in hold; 12 V, fused, guarded, inside release |

### Still awaiting Amish

9. Wall material: fired brick, mud brick or block. No recommendation; fired brick remains the working choice.
10. First co-design partner, region and crop mix. No recommendation; partners are picked per area later.

### Cross-repo actions

None. No decision needs another repo to change.

### Safety concerns

- Dry rice husk is combustible: keep the cavity capped with mortar, keep hot work and flames away from the walls during building, and run solar wiring in conduit where it passes the wall top (added to ZBX-PRC-001 v0.4).
- The husk must stay dry and closed to termites and rodents; a wet or infested fill loses its insulation and can harbor mold.
- All earlier concerns stand: roof uplift, inside door release, *Legionella* in the sump, battery, fan guards, not for cold-chain products.

### TRL 4

TRL 4 remains on hold by Amish's instruction. No TRL 4 work was created. Confirming the husk supply and the local design wind speed, crate liner trials, and a pad and fan test article all wait for a partner and for TRL 4 to be released.

## Session 2026-09-26: sources strengthened

Amish asked for the weaker sources to be fixed. Every replacement below was fetched and checked against the claim it supports.

| Where | Claim | Old source | New source |
| --- | --- | --- | --- |
| README, Northern Nigeria row; ZBX-PRB-001 gap 1 | ColdHubs pay-per-crate solar cold rooms at markets and farm clusters | Wikipedia, "ColdHubs" | [ColdHubs](https://coldhubs.com/) official site and [IFPRI](https://www.ifpri.org/blog/coldhubs-addressing-crucial-problem-food-loss-nigeria-solar-powered-refrigeration/) (about $0.50 per crate per day); zeer revival cited to *TIME* |
| README, Australia row | Coolgardie safe | Wikipedia, "Coolgardie safe" | [Western Australian Museum](https://visitwanderland.com.au/explore/golden-outback/warden-finnertys-residence/coolgardie-safe). The unverified "3 to 9 °C below the air" figure and the uncited remote supply claim were removed |
| README, What sparked the idea; ZBX-PRB-001 prior work | Bah Abba pot-in-pot cooler | Wikipedia, "Pot-in-pot refrigerator" | Verploegen, Sanogo and Chagomoka, [MIT D-Lab Mali evaluation](https://d-lab.mit.edu/sites/default/files/inline-files/GHTC%20-%20Evaluation%20of%20Low-Cost%20Evaporative%20Cooling%20Technologies%20for%20Improved%20Vegetable%20St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) (popularized in Nigeria from 1995) and [*TIME*, Best Inventions of 2001](https://content.time.com/time/specials/packages/article/0,28804,1936165_1936254_1936632,00.html). The unverified "first batch of 5,000" and the award year were dropped; the name now follows the Rolex and D-Lab spelling, Mohammed |
| ZBX-PRB-001 gap 3 | Evaporative cooling weakens in humid air | Wikipedia, "Evaporative cooling chambers" (25 °C, 40 % RH rule of thumb) | MIT D-Lab Mali evaluation: peak cooling up to 10.4 °C below 40 % RH, 4.2 °C above 70 % RH |
| README, Mali row; ZBX-PRB-001 prior work | Brick chamber cooling in Mali | MIT News only | MIT D-Lab paper added as the primary source alongside MIT News |

The inspiration event is unchanged; its line in the portfolio `INSPIRATIONS.md` was corrected to the verified facts. ZBX-PRB-001 moved to v0.5. No budget change for ZeerBox.

## Session 2026-09-26: product appearance model and photoreal renders

Amish chose this repo for the first batch of product renders on 2026-09-26. This session adds an appearance model for photoreal renders; it changes no dimension, calculation, drawing or BOM line.

### What was done

- `cad/src/product_model.py` (new): `product_parts()`, `TITLE` and three `RENDER_VIEWS` (hero, exploded, detail). It imports `PARAMS`, `derived()` and `build_parts()` from `cad/src/model.py` and reuses the walls, cavity fill and rack geometry directly. It adds:
  - Structure: brick bed joints on the outer leaf, a rendered plinth band, timber lintel faces over the door and pad openings, a timber fascia on the ceiling edge, a corrugated galvanized roof sheet with purlins, rafters and screws, galvanized posts with cap plates and concrete footing collars.
  - Solar panel: aluminum frame, 36 cells with busbars, backsheet, junction box and four mounting legs, in the model.py position and tilt.
  - Cooling kit: cellulose pad with a fluted face in an aluminum frame with screws, PVC drip header with end caps and tee, galvanized gutter with outlet; 60 L drum with hoops, lid, fittings and label, feed and return hoses; fan housings, blades, hubs, finger guards and gravity shutters; IP65 controller with lid parting line, clear lid window over the board, terminals and memory card, glands, name plate, a lit green mode lamp and the outside sensor in a stacked-plate radiation shield; ventilated power box with rain hood, door, window onto the charge controller (lit display and charging light), battery, hinges, hasp and label; a PVC cable conduit with clips.
  - Door with seal, hinges, handle and sign; slatted rack shelves; open ventilated crates with produce.
  - Context: a compact patch of ground and the shared clay mannequin (1.75 m, standing) by the door.
- Views: hero from the front right at about 30 deg (pad, sump and panel visible, person by the door); exploded from the front right at about 28 deg; detail of the cooling kit alone from the door end at about 18 deg (controller, fans, power box, pad and sump).
- `README.md`: the hero image now points to `media/render-hero.png`, with an exploded render link. The render files are produced separately.

### Differences from model.py (appearance only)

Main dimensions, positions and interfaces are unchanged. The items below go beyond model.py and are recorded for Amish.

1. **Roof framing.** model.py runs the posts up to the roof sheet; the appearance model adds timber purlins and rafters under the sheet, so the posts stop under the rafters. The corrugated sheet stays inside model.py's 25 mm roof envelope. Proposed, awaiting Amish. Recommendation: add purlins and rafters to model.py at the next CAD revision so the drawing shows how the sheet is carried.
2. **Clear windows on the controller lid and power box door.** Decided 2026-10-02: clear lid on the controller only, plain power box door; carried into the appearance model. The BOM calls for an IP65 box and a ventilated shaded box, with no window. The windows show the internals in the renders. Proposed, awaiting Amish. Recommendation: keep the controller window (a clear-lid IP65 box is a stock part and lets users read the board lights); drop the power box window if a partner prefers a plain steel door, since the battery box must stay shaded.
3. **Mode lamp position.** Decided 2026-10-02 and added to model.py. model.py does not place the three-color mode lamp; the precis puts it by the door. The appearance model puts it on top of the controller box, which sits beside the door. Proposed, awaiting Amish. Recommendation: accept, and add it to model.py.
4. **Radiation shield shape.** Decided 2026-10-02 and added to model.py. Stacked round plates, 46 mm across, in place of model.py's 40 x 40 x 60 mm block. Proposed, awaiting Amish. Recommendation: accept; the envelope grows by 3 mm a side.
5. **Plinth render band and lintel faces.** A 10 mm cement render band 300 mm high around the base and timber lintel faces 6 mm proud over the door and pad openings (lintels are in BOM line 1 but not modeled). Proposed, awaiting Amish. Recommendation: accept the lintels; treat the plinth render as optional, a finish a local mason can choose.
6. **Hose and conduit routing.** The return hose runs down from the gutter outlet and across to the drum instead of model.py's straight diagonal; a PVC conduit (BOM line 14, not modeled in model.py) links the power box, the controller and the ceiling edge. Proposed, awaiting Amish. Recommendation: accept as a routing sketch only; wiring and plumbing stay unmodeled at TRL 3.
7. **Footing collars.** A 30 mm concrete collar shows the top of each footing at ground level; the footings themselves (ZBX-CAL-001) are below ground and not drawn. No change to the footing size.

### Status

Appearance only: no tolerances, no fabrication detail and no TRL 4 work. `trl` stays 3 and TRL 4 remains on hold by Amish's instruction.

## Session 2026-09-27: kit 1.5.0 and image quality

- Kit 1.5.0 synced: STANDARDS v1.5 (sections 12 to 15: product renders, storefront images and image quality, public release, authorship and signing), `.kit/cards.py`, `.kit/image_qc.py`, `.kit/release_gate.py`, issue templates, and the `/render-product` and `/release` commands. `CLAUDE.md` now matches `.kit/CLAUDE.md`.
- Every `media/render-*.png` recaptioned from its original render with the new layout: the title, concept label and repository sit in a band above the render and the view note in a band below it, each line wrapped to the image width, so no text overlaps other text or the render or runs off the image. `media/card.png` and `media/social-preview.png` regenerated with the same rules.
- `python .kit/image_qc.py` and `python .kit/release_gate.py` pass. trl stays 3.

## Session 2026-10-02: design for construction and prototype build plan (kit 1.7.0)

Amish approved the build plan format on 2026-09-30 and asked for it across all repos, with open decisions kept in a separate register, and wrote: "If you are realising that the design cannot be built as per concept - fix the design assumptions to match and be physically feasible as you draw the illustrations." This session made ZeerBox constructable and wrote its build plan. The repo stays at TRL 3.

### What was done

- Kit 1.7.0 installed (`.kit/`, `.claude/commands/`); `CLAUDE.md` now matches `.kit/CLAUDE.md`.
- `cad/src/model.py` rebuilt as a component model (every made, bought or fixed part, with the faces it sits on) and a constructability check, `python cad/src/model.py --check`: 7,816 checks (no overlaps except posts cast in their footings, 39 named joints touching, no floating piece, 7 clearances), all pass. STEP and STL re-exported.
- `docs/decisions/0003-design-for-construction.md` (ZBX-DDR-003 v0.1, Draft): every change below with its reason, made under Amish's 2026-09-30 instruction to make the design physically buildable; open for his review.
- `docs/05-build-plan.md` (ZBX-BLD-001 v0.1) and `docs/06-design-decisions.md` (ZBX-DEC-001 v0.1), from the kit templates.
- `cad/src/build_plan_media.py`: overview, setting-out plan, 18 making sketches (`cad/drawings/ZBX-DWG-101` to `118`), 9 joint close-ups, 26 assembly step pictures and a block wiring diagram, in `docs/05-build-plan/`. Every picture was looked at and the unclear ones redrawn.
- `bom/bom.csv`: lines 15 (strip footing), 16 (door lining, stops and fan box), 17 (roof beams and purlins) and 18 (panel mounting frames) added; lines 1, 3, 4, 5, 6, 8, 10 and 12 respecified and repriced. `bom/bom-notes.md` updated.
- `docs/04-calcs/sizing.py` and ZBX-CAL-001 v0.3: wall openings without fan holes, framing weight in the uplift, roof and ceiling members checked (Table 6a), new cost groups, R12 against the value-engineering target.
- ZBX-REQ-001 v0.5 and ZBX-PRC-001 v0.5 updated; general arrangement ZBX-DWG-001 Rev P3 (`cad/src/sheets.py`); concept media regenerated (`cad/src/concept_media.py`; the concept views leave out the below-ground footings).
- `project.yaml`: `design_state: constructable`; DDR-003, the build plan and the register added to `trl_evidence`. `budget_usd` unchanged. README: build plan and register links and a "Building the prototype" section.

### Design changes made for construction (ZBX-DDR-003)

1. **Fans moved from the front wall to a ceiling fan box** at the door end over the aisle: the wall holes left 50 mm brick piers beside the door and at the corners. The fans still exhaust at the door end with the pad opposite.
2. **Roof framing added**: two 75 x 150 mm beams on welded, sloped post cap plates; five 50 x 150 mm purlins with hurricane ties; anchor bars through the post feet. 100 mm purlins would be over-stressed (11.6 MPa).
3. **Wall strip footing** 450 x 250 mm with a damp-proof strip, which the calculation assumed but the model and BOM lacked.
4. **Lintels, reveal linings and a door frame**: a hardwood lintel over each leaf at both openings, 20 mm linings closing the cavity, brick openings 40 mm larger, stop beads, hinges, a 74 mm door (as the U value assumed) opening outward.
5. **Framed ceiling**: joists with cleats, insulation, vapor sheet and boards in the same 120 mm, strapped to the walls; a brick capping course over the cavity.
6. **Racks rebuilt**: rails on the inside faces of the posts and slats across them (the posts used to pass through the shelves); wall brackets.
7. **Pad assembly**: board frame on wall battens, support and retaining bars, header lying on the pad, gutter on brackets.
8. **Panel mounting frames** in aluminium, screwed into the purlins; the panel had no mount and floated 150 mm above the roof. Panel centre 50 mm down the slope and 100 mm higher.
9. **Sump drum moved 190 mm** to sit fully under the roof.
10. **Outside sensor arm** added.

### Key results

- Cooling unchanged: store 24.3 °C, 10.7 K below 35 °C outside (9.8 to 11.4 K); 81 % RH; 563 m³/h; 36 L/day; 372 Wh/day. Heat load 443 W (was 442 W).
- Roof: uplift per post 1.94 kN (was 2.23 kN) with the framing weight; footing factor 1.81.
- Cost: value-engineering target USD 300 for the kit; estimated cost of the constructable design USD 299 (USD 1 under the target). Structure USD 574, costed separately (was USD 355); store USD 873.
- Requirements: 7 met (3 by review), R12 under its target, **R3 at risk** (81 %, 77 % unfavorable), none not met, R6, R10, R11 not verifiable at TRL 3.

### Proposed, awaiting Amish

All open decisions are in the register ZBX-DEC-001: accept DDR-003; fan position (ceiling fan box recommended); exhaust into the roof space; wall material; partner; and the 2026-09-26 appearance items.

### Renders still to be made

The photoreal renders (`media/render-*.png`), `media/card.png` and `media/social-preview.png` are made on Amish's Mac. The appearance model and render scenes are current (see the 2026-10-02 section on approved follow-ups).

### Safety concerns

- Work at height on the ceiling and roof (build plan stop S2); the roof must be tied and screwed down the day it goes on.
- The door opens outward with an inside push latch and no outside lock (stop S7).
- Fans are now in the ceiling at 2.1 m; guards on both faces remain required.
- All earlier concerns stand: battery, *Legionella* in the sump, combustible husk, not for cold-chain products.

### Recommended next step

Amish to review DDR-003 and the register. TRL 4 (building to this plan) stays on hold until he releases it.

## Session 2026-10-02: open decisions decided

Amish, 2026-10-02: "APPROVED: The open decisions from the last wave (TremorTrace to ZeerBox) came in after the review and aren't on the page either." This approves the recommendation written for each open decision in the design decisions register (ZBX-DEC-001), as he did for the other 555 open decisions ("i approve your recommendations for all 555 open decisions."). trl stays 3; no build or test work was done, and the model, BOM quantities and prices, and pictures are unchanged.

### Decisions recorded

Ten decisions, all moved to Decisions made in ZBX-DEC-001, dated 2026-10-02:

1. Design for construction accepted: the changes C1 to C10 of ZBX-DDR-003, as made.
2. Fan position: the two fans stay in the ceiling fan box at the door end, as modelled.
3. Exhaust into the roof space accepted, with a check at TRL 4 that moist air does not drift back to the pad; a short duct past the roof edge is added only if it does.
4. Wall material: fired brick, as modelled and calculated.
5. First co-design partner, region and crop mix: a group that has already field-tested evaporative cooling chambers with vegetable growers; the first candidate to approach is MIT D-Lab's evaporative cooling team, with a dry-season vegetable area of Mali as the first candidate region and tomatoes, peppers and okra as the crop mix, leafy greens on a separate rack.
6. Clear window in the controller lid only; the power box has a plain door.
7. Mode lamp on top of the controller box beside the door, added to the model.
8. Outside sensor shield: stacked round plates 46 mm across.
9. Plinth render band: an optional 10 mm finish 300 mm high, the mason's choice.
10. Hose and conduit routing accepted as sketched in the build plan, routed on site.

### Documents changed

- `docs/06-design-decisions.md` (ZBX-DEC-001 v0.2): open decisions moved to Decisions made.
- `docs/decisions/0003-design-for-construction.md` (ZBX-DDR-003 v0.2): acceptance recorded in the status line; A1 and A2 decided (record stays Draft).
- `docs/decisions/0001-trl2-review-decisions.md` (ZBX-DDR-001 v0.3) and `docs/decisions/0002-recommendations-accepted.md` (ZBX-DDR-002 v0.2): items 9 and 10 recorded as decided.
- `docs/01-problem.md` (ZBX-PRB-001 v0.7): partner, region and crop mix answered.
- `docs/02-concept.md` (ZBX-PRC-001 v0.6): design for construction accepted, wall material decided, partner next step.
- `README.md`: the build plan paragraph says ZBX-DDR-003 is accepted and the decisions are all made.

### Follow-up actions to carry approved decisions into the design

1. Decision 7 (model): Add the three-color mode lamp on top of the controller box beside the door to the model, with its hole in the box.
2. Decision 8 (model): Replace the 40 x 40 x 60 mm block of the outside sensor shield with stacked round plates 46 mm across in the model.
3. Decision 6 (BOM): Name a clear-lid IP65 box for the controller and a plain-door box for the power box in the BOM specifications (no price change expected).
4. Decisions 7 and 8 (pictures): Regenerate the general arrangement, concept media and the build plan pictures of the controller box and sensor arm for the mode lamp and the plate shield.
5. Decision 5 (docs): Approach MIT D-Lab's evaporative cooling team about a site in Mali's dry-season vegetable areas, and confirm the crop mix and crate size with the growers there.

### Points found in the review

- None.

## Session 2026-10-02: approved follow-ups carried out

Amish approved on 2026-10-02 that every follow-up action from the open-decision sign-off be carried out. trl stays 3.

### Follow-ups

1. Done: mode lamp and its hole added to `cad/src/model.py` (controller box now hollow; component `mode_lamp`; contact and clearance checks). 7,857 checks, 0 failed. STEP and STL regenerated.
2. Done: outside sensor shield is six round plates 46 mm across on a stud and strip arm.
3. Done: `bom/bom.csv` line 9 names the clear-lid IP65 box, 22 mm lamp and six-plate shield; line 11 names a plain-door box. No price change; `bom/bom-notes.md` updated.
4. Done: GA ZBX-DWG-001 Rev P4, concept media, build plan overview, step 25 and wiring picture regenerated. `drawing.py --check-text` reports no hits.
5. Not done: outreach to MIT D-Lab and the Mali growers is Amish's action.

Done 4 of 5.

### Results

- Requirement status changes: none. Value-engineering target: USD 300. Estimated cost of the constructable design: USD 299 (USD 1 under the target). `budget_usd` unchanged. Mass change is negligible (a lamp and six small plates).
- Appearance model `cad/src/product_model.py` rewritten from `model.py` components (it had broken at the ceiling fan change). Render scenes exported to `/home/claude/renders/zeerbox`: hero, exploded, detail, plus `zeerbox__jobs.json`.

### Documents changed

- `docs/05-build-plan.md` v0.2, `docs/02-concept.md` v0.7, `docs/decisions/0003-design-for-construction.md` v0.3 (C11 and C12 added); this note; `cad/src/sheets.py`, `build_plan_media.py`.

### Cross-repo actions

- None found for this repo. The partner approach (follow-up 5) is outreach by Amish.

### Proposed, awaiting Amish

- Appearance only: the cable conduit to the fan box is drawn over the ceiling boards for visibility, whereas the build plan runs it under them.

### Safety concerns

- Unchanged.

## 2026-10-02: photoreal renders redone on the constructable design

Rendered with Blender Cycles on Amish's Mac from the updated appearance model; captioned with `.kit/photo_caption.py`; `media/card.png` and `media/social-preview.png` regenerated with `.kit/cards.py`. Views: hero, exploded, detail. image_qc passes. Appearance deviations are those logged above as proposed, awaiting Amish.

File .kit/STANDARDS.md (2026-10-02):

---
doc_id: OHP-STD-001
title: Documentation and drawing standard
project: Open Hardware Portfolio
doc_type: Standard
version: "1.7"
status: Released
date: 2026-09-30
author: Amish Chadha
license: CC-BY-SA-4.0
revisions:
  - version: "1.0"
    date: 2026-09-24
    author: Amish Chadha
    change: First release of the standard
  - version: "1.1"
    date: 2026-09-24
    author: Amish Chadha
    change: Adopt Technology Readiness Levels (section 9) for project maturity
  - version: "1.2"
    date: 2026-09-24
    author: Amish Chadha
    change: Portfolio phase cap (section 10), concept media standard (section 11), CLAUDE.md guardrails
  - version: "1.3"
    date: 2026-09-24
    author: Amish Chadha
    change: Scale figure, interactive 3D viewer and flow diagrams added to concept media; session slash commands
  - version: "1.4"
    date: 2026-09-26
    author: Amish Chadha
    change: Every sheet and render names the project and its GitHub repository; overall dimensions, ISO centre lines and 300 dpi PNG on sheets; titles name the device and view labels state the viewing direction; optional photoreal renders with Blender
  - version: "1.5"
    date: 2026-09-27
    author: Amish Chadha
    change: Product renders (section 12), storefront images and image quality check (section 13), public release and release gate (section 14), authorship, citation and commit signing (section 15)
  - version: "1.6"
    date: 2026-09-29
    author: Amish Chadha
    change: Licensing metadata with REUSE (section 16), Zenodo DOI and Software Heritage archiving (section 17), release gate checks REUSE and a single CITATION.cff license, archive.py
  - version: "1.7"
    date: 2026-09-30
    author: Amish Chadha
    change: Concept and constructable design states; design decisions register (DEC) kept apart from the build plan; prototype build plan (BLD, section 18) with pictures by component is required TRL 3 evidence; every repo targets TRL 3 during the populate phase; build_views.py; /to-trl3 and /build-plan commands
---

# Documentation and drawing standard

Every project in the portfolio uses this standard, so that each precis, write-up and sketch looks the same and carries its own version history. The standard ships as a kit in each repo's `.kit/` folder. The kit version is in `.kit/KIT_VERSION`.

## 1. Document types and IDs

Every controlled document has a unique ID in the form `PRJ-TYP-NNN`.

- `PRJ` is the three-letter project code listed in section 7.
- `TYP` is the document type code from the table below.
- `NNN` is a sequence number within that project and type, starting at 001.

| Code | Type | Typical file |
| --- | --- | --- |
| PRC | Design precis | `docs/02-concept.md` |
| PRB | Problem statement | `docs/01-problem.md` |
| REQ | Requirements | `docs/03-requirements.md` |
| CAL | Calculation or sizing note | `docs/04-calcs/*.md` |
| DDR | Design decision record | `docs/decisions/*.md` |
| BOM | Bill of materials | `bom/bom.csv` |
| DWG | Drawing or sketch sheet | `cad/drawings/*.svg` |
| BLD | Prototype build plan (section 18) | `docs/05-build-plan.md` |
| DEC | Design decisions register (section 18) | `docs/06-design-decisions.md` |
| TST | Test plan or test report (front matter adds `environment: lab` or `relevant`) | `docs/05-tests/*.md` |

Example: `TBK-PRC-001` is the ThermaBrick design precis.

## 2. Revision scheme

| Artifact | While in draft | When released | Change after release |
| --- | --- | --- | --- |
| Documents | 0.1, 0.2, 0.3 ... | 1.0 | 1.1 for minor edits, 2.0 for a design change |
| Drawings | Rev P1, P2 ... (preliminary) | Rev A | Rev B, C ... |

- Every change to a controlled document adds a row to its revision history before the commit.
- The `version` field in front matter always equals the newest row in `revisions`. The renderer rejects a document where they differ.
- Status is one of `Draft`, `In review`, `Released` or `Superseded`. Draft and In review documents print with a status band on every page.
- Every release is tagged in Git as `<doc_id>/v<version>`, for example `TBK-PRC-001/v1.0`. Drawings are tagged `TBK-DWG-001/revA`.
- Git history is the full audit trail. The in-document revision table is the human-readable summary.

## 3. Document front matter

Every Markdown document under version control starts with this block:

```yaml
---
doc_id: TBK-PRC-001
title: ThermaBrick design precis
project: ThermaBrick
doc_type: Precis
version: "0.1"
status: Draft
date: 2026-09-24
author: Amish Chadha
license: CERN-OHL-S-2.0
revisions:
  - version: "0.1"
    date: 2026-09-24
    author: Amish Chadha
    change: Initial draft
---
```

Quote version numbers so YAML keeps `1.0` as text instead of turning it into a number. List revisions newest last.

## 4. Writing style

- Chicago Manual of Style.
- No em dashes. Restructure the sentence instead.
- Lead each section with its conclusion, then support it.
- SI units throughout, in the form `12 kW`, `450 °C`, `3.2 m`. Imperial values may follow in parentheses.
- Number every figure and table ("Figure 2", "Table 1") and give each a caption.
- State every assumption in the calculation that depends on it.
- Put safety notes in a blockquote starting with **Safety:**.

## 5. Visual identity

| Element | Specification |
| --- | --- |
| Typeface | IBM Plex Sans for text, IBM Plex Mono for code and values (SIL Open Font License, bundled in `.kit/fonts`) |
| Ink | `#111827` |
| Secondary text | `#4B5563` |
| Rules and grid | `#D1D5DB` |
| Accent (one only) | `#0F766E` teal |
| Document page | US Letter, 20 mm margins |
| Drawing sheet | ANSI B landscape (431.8 x 279.4 mm) |
| Footer | Document ID, version, status, license and designmolecule.com on every page |

## 6. Drawing and sketch conventions

- Units are millimeters unless the title block says otherwise.
- Third-angle projection, marked with the symbol in the title block.
- Line weights: visible outlines 0.5 mm, hidden lines 0.25 mm dashed, center lines 0.18 mm chain.
- The title block contains the project, title, drawing number, revision, scale, units, projection, sheet, author, date, material or notes, and license.
- Every sheet and every render names the project and its GitHub repository (from `repo:` in `project.yaml`), at the top of the sheet and in the title block, so a printed or forwarded sheet is never anonymous.
- The drawing title names the device, not only the drawing type (for example "Handheld near-infrared resin scanner: general arrangement").
- Every view label states its scale and viewing direction (for example "Scale 1:1; side elevation looking along +Y"), and every isometric or render states where it is seen from.
- Orthographic views generated with `add_ortho` carry overall dimensions (length and depth on the top view, height on the front view) and ISO 128 centre lines on cylinders; hidden lines are dashed. Tolerances are not shown before TRL 4.
- Sheets are exported as SVG, PDF and a 300 dpi PNG.
- The revision table in the top right of the sheet lists every revision.
- Concept sketches use the same sheet and title block and carry the label "CONCEPT, NOT FOR FABRICATION".
- Geometry comes from `cad/src/*.py` (build123d). Sheets are generated by `.kit/drawing.py` and never edited by hand.

## 7. Project codes

| Code | Project | Code | Project | Code | Project |
| --- | --- | --- | --- | --- | --- |
| TBK | ThermaBrick | PCF | PicoFlow | HLT | HelioLite |
| CCB | CharCube | DRN | DustRunner | TRT | TremorTrace |
| STC | StepCue | FXH | FlexHand | CPD | ColdPod |
| SCL | SunClave | STR | SteamRoot | GGD | GrainGuard |
| SDL | SeedLine | ZBX | ZeerBox | RMS | RootMesh |
| DWD | DewDrive | SSK | StillStack | PPR | PotPress |
| WWT | WaterWatch | LMF | LumaFlow | FCL | FieldCell |
| CNP | ConePro | CVC | CulvertCrawl | EGD | EmberGuard |
| SNF | SnapFrame | CGM | CargoMule | SCM | StepClimber |
| SWC | SwapCell | PLP | PalletPilot | FTK | FlatTrike |
| WWK | WaterWalker | GRR | GrowRider | SSP | SunSpoke |
| SGN | StepGen | PBX | PowerBox | WML | WasteWise-ml |
| WSC | WasteWise Scan | RFE | ReflowEconomy | | |
| OHP | Portfolio-wide | | | | |

## 8. Build and publish

- `python .kit/render.py` checks every controlled document and renders it to `docs/pdf/<doc_id>_v<version>.pdf`.
- `python .kit/drawing.py` (called from each project's `cad/src/sheets.py`) builds drawing sheets as SVG and PDF in `cad/drawings/`.
- The GitHub Action in `.github/workflows/docs.yml` runs the checks on every push and attaches PDFs to a GitHub Release whenever a release tag is pushed.
- Public releases follow section 14: `python .kit/release_gate.py` must pass, and the release tag is `v0.<TRL>.0` (for example `v0.3.0` at TRL 3).

## 9. Technology Readiness Level (TRL)

Each project states its maturity as a Technology Readiness Level on the NASA and US DOE 1 to 9 scale. The TRL rates this specific design, not the underlying technology. A sand battery is commercial elsewhere, but a new sand battery design starts at TRL 2 until evidence shows otherwise.

| TRL | Definition | Evidence the repo must contain |
| --- | --- | --- |
| 1 | Basic principles observed | Problem statement (PRB) |
| 2 | Technology concept formulated | Draft precis (PRC) and requirements (REQ) |
| 3 | Analytical or experimental proof of concept | Calculation note (CAL), working build123d model with STEP export, drawing sheet (DWG), priced BOM with every unit cost filled in, prototype build plan (BLD) with pictures, `design_state: constructable` |
| 4 | Components validated in the lab | Test report (TST) with `environment: lab`, build log entries |
| 5 | Validated in a relevant environment | Test report (TST) with `environment: relevant` |
| 6 | System prototype demonstrated in a relevant environment | Precis at version 1.0 or later with status Released, a drawing at a lettered revision (Rev A or later), and a system-level TST with `environment: relevant` |
| 7 to 9 | Operational demonstration through proven in service | Beyond portfolio scope; claim only with a named deployment partner and evidence |

Rules:

- `project.yaml` records `trl` (current level), `trl_target` (the level the current effort aims for) and `trl_evidence` (the files that support the claim).
- `python .kit/render.py --check` fails if the evidence for the claimed TRL is missing. CI runs this check on every push.
- Documentation alone cannot go past TRL 3. TRL 4 and above require hardware and a test report.
- TRL and visibility are independent. A repo can be public at TRL 3 as a documented design ready to build.
- A change of TRL is recorded in the build log with the date and the evidence that justified it.

## 10. Portfolio phase and TRL cap

`.kit/PHASE.yaml` sets the current phase. During the **populate** phase every repo is capped at **TRL 3**: `trl` and `trl_target` may not exceed 3, and the check fails if they do. Every repo targets the cap: `trl_target` must equal 3, so a new repo is taken all the way to TRL 3 (scaffold, populate and advance, see `/to-trl3`). Work that belongs to TRL 4 or later (building or testing hardware, test articles, test plans and reports, build-log entries, purchasing lists, PCB layouts) must not be started. The prototype build plan (BLD, section 18) is TRL 3 paper work and is required. Where it already exists it is kept, flagged in the check output, and not extended. Only Amish changes `PHASE.yaml`.

Every repo carries a `CLAUDE.md` with the working rules for AI sessions: the TRL cap, decision rights (nothing is recorded as decided unless Amish decided it), one step per session, and a mandatory `docs/REVIEW.md` before stopping.

## 11. Concept media

Every repo at TRL 2 or above explains its idea visually. Media are generated from a build123d massing model with `.kit/concept.py`, never drawn by hand, so they stay in step with the design.

| File | Required | Purpose |
| --- | --- | --- |
| `media/hero.png` | TRL 2+ | Shaded isometric render with a 1.75 m person for scale; the website card image |
| `media/concept-blueprint.png` and `.pdf` | TRL 2+ | Blueprint concept sheet: orthographic and isometric views, scale, key figures, title block |
| `media/model.glb` and `media/viewer.html` | TRL 2+ | Interactive 3D viewer (glTF plus model-viewer) for the website |
| `media/cutaway.png` | When the inside matters | Section view showing internal parts |
| `media/exploded.png` | Recommended | Exploded view with numbered callouts matching the BOM |
| `media/flow.png` | When energy or material moves | System, energy or material flow diagram with losses |

Session commands in `.claude/commands/` (`/populate`, `/advance-trl3`, `/rein-in`, `/refresh-media`) carry the standard prompts, so every Claude Code session starts from the same instructions.

At TRL 2 a massing model is enough: correct overall proportions and main components. All concept media carry "CONCEPT, NOT FOR FABRICATION". The check warns when required media are missing at TRL 2 and fails at TRL 3.

## 12. Product renders

Every repo at TRL 3 shows the product as it would look, not only as a massing model.

- `cad/src/product_model.py` is the appearance model. It defines `product_parts()` (named parts with a shape and a material), `TITLE` ("Name: what it is") and `RENDER_VIEWS`. It is for renders only: every main dimension comes from `cad/src/model.py`, never typed in again.
- Where the appearance model departs from `model.py` (a chamfer, a label, a fastener drawn for realism), record the deviation in `docs/REVIEW.md` as "Proposed, awaiting Amish".
- Scale comes from context, not from a floating figure: a hand or forearm for handheld objects, and the posed mannequin (`mannequin()` in `.kit/context_parts.py`: stand, walk, push, ride, sit, reach) for anything a person uses at body scale.
- Renders are made with `.kit/export_views.py` (one scene per view) and `.kit/photoreal.py` (Blender Cycles), then captioned with `.kit/photo_caption.py`. Files are `media/render-<view>.png`; `media/render-hero.png` is required.
- Every caption names the project, the repository and the viewing direction, and carries "CONCEPT, NOT FOR FABRICATION".
- Captions never sit on the render. `.kit/photo_caption.py` adds a header band (title, concept label, repository) above the render and a footer band (view note) below it, wraps every line to the image width, and steps the font down to a floor before adding a line.
- The README opens with `media/render-hero.png`.
- Software-only and scene repositories (no single product) may use a scene render as the hero instead of a product model.

## 13. Storefront images

Two images, both made from `media/render-hero.png` by `python .kit/cards.py .`:

| File | Size | Purpose |
| --- | --- | --- |
| `media/card.png` | 800 x 800 | Square thumbnail for the organization profile page |
| `media/social-preview.png` | 1280 x 640, under 1 MB | GitHub social preview, shown when a repository link is shared |

- The social preview shows the area, name, one-line description, the first sentence of the pitch, the brand line and the repository address. Design Molecule repos read "Design Molecule · open hardware concept, TRL n"; OpenRatio repos read "OpenRatio · research and educational prototype, TRL n".
- GitHub has no API for the social preview. Upload it under the repository's Settings, Social preview, on release day.
- Regenerate both images whenever `render-hero.png` changes.

### Image quality

Every render, card and social preview must be clear and readable. `python .kit/image_qc.py` checks each one, and the release gate blocks on any failure:

| Check | Rule |
| --- | --- |
| Layout | Made by the current `photo_caption.py` or `cards.py`, which store the text layout in the PNG |
| Text inside the image | Every line at least 1.2 % of the image width from each edge; nothing runs off the side |
| No overlap | No line of text touches another line, and no caption text sits on the render |
| Text size | Render captions at least 1.05 % of the image width in pixel height (17 px at 1600 px); social preview text at least 16 px |
| Resolution | Renders at least 1200 px wide; card 800 x 800; social preview 1280 x 640 and under 1 MB |
| Sharpness | The render is not blurred or upscaled (edge sharpness at least 15 on the `image_qc.py` scale) |

Long titles and notes wrap to more lines rather than shrinking below the floor. The social preview shortens the pitch sentence with an ellipsis only if it cannot fit at the smallest size.

## 14. Public release

A repository goes public only when Amish approves it, and only after `python .kit/release_gate.py` passes. The gate checks:

1. `render.py --check` passes (document control, TRL cap, concept media).
2. Storefront: hero render, card, social preview under 1 MB, README leading with the hero, and every image passing the image quality check (section 13).
3. Issue templates in `.github/ISSUE_TEMPLATE/`: question, build report, design suggestion. The build report template restates that the design is a TRL 3 concept, not released for fabrication (OpenRatio: a research and educational prototype, not a medical device).
4. `CITATION.cff` valid, with an author ORCID.
5. License files match `project.yaml`.
6. No em dashes in the repository's own text.
7. BioMedical and OpenRatio repos use soft, non-clinical wording: "research and educational prototype, not a medical device".
8. No secrets anywhere in the history (gitleaks).
9. No links to sibling repositories that are still private.
10. REUSE files present (`REUSE.toml`, `LICENSES/`, `.github/workflows/reuse.yml`) and `reuse lint` passes (section 16).
11. `CITATION.cff` names exactly one license, because Zenodo rejects a list (section 17).

It warns, without blocking, when the README lacks a Safety heading or a "not for fabrication" statement, when `CITATION.cff` has no DOI yet, and when the README lacks the Zenodo DOI, REUSE or Software Heritage badge, so a person can confirm.

On release day, per repository:

- A signed, annotated tag `v0.<TRL>.0` on `main`.
- A GitHub release with short notes (what it is, TRL, status, licenses, how to cite) and a design pack, `<repo>-v0.<TRL>.0-design-pack.zip`, holding `cad/step`, `cad/drawings`, `docs/pdf`, `bom`, README, licenses and `CITATION.cff`.
- Description from the first sentences of `pitch` (350 characters at most), website `https://designmolecule.com` (OpenRatio: `https://openratio.ai`), topics from `project.yaml`.
- Before the first release, the repository is switched on in Zenodo (section 17), so the release is archived and gets a DOI.
- Visibility switched to public last, after the release exists.
- The social preview uploaded and the organization profile updated with the new cards.
- After the release: the concept DOI written to `CITATION.cff` and a Software Heritage save requested (section 17).

The internal working files (`CLAUDE.md`, `.kit/CLAUDE.md`, `.claude/commands/`, `docs/REVIEW.md`) stay public, and open "Proposed, awaiting Amish" items stay visible as open questions (Amish, 2026-09-27).

## 15. Authorship, citation and signing

- Amish Chadha is the author of every design, ORCID 0009-0000-8079-7141. Commits are authored as Amish Chadha <amish@designmolecule.com>.
- `CITATION.cff` lists Amish (with ORCID) first, then any credited contributors; `CONTRIBUTORS.md` and the README Credits section agree with it.
- `CITATION.cff` names one license: the hardware license (CERN-OHL-S-2.0), or the software license in a software-only repository. The full split between hardware and software licenses lives in `REUSE.toml` and the README. Once the repository is archived, `CITATION.cff` carries the concept DOI in `doi:`.
- Work done with Claude carries the trailer `Co-Authored-By: Claude <noreply@anthropic.com>` (with the model name), and the README Credits section says designs are developed with AI assistance.
- Every commit and tag pushed to GitHub is signed with Amish's SSH signing key, so GitHub shows it as Verified. Commits prepared elsewhere are re-signed on Amish's Mac before they are pushed.
- Once a repository is public, its history is never rewritten.

## 16. Licensing metadata (REUSE)

Every file states its copyright and license in a machine-readable way, following the REUSE Specification 3.3 (https://reuse.software). A repository is set up with:

```
python .kit/archive.py reuse
```

This writes three things and adds the REUSE and Software Heritage badges to the README badge line:

- `REUSE.toml`, built from the licenses in `project.yaml`. Everything is under the hardware license by default. Scripts, firmware, notebooks, web viewers, workflows and agent commands are under the software license. `cad/` and `electronics/` stay under the hardware license even where they are written as Python. The bundled IBM Plex fonts are OFL-1.1 (IBM Corp.). Copyright is "<first commit year> Amish Chadha".
- `LICENSES/`, with the full text of each license used (`reuse download`). The root `LICENSE` and `LICENSE-SOFTWARE` files stay for GitHub's license detection.
- `.github/workflows/reuse.yml`, which runs the REUSE check (fsfe/reuse-action) on every push and drives the README badge.

A new kind of file that falls outside these rules gets a new annotation in `REUSE.toml` rather than a header comment. `reuse lint` must pass before every commit that adds files, and the release gate enforces it.

## 17. Archiving and DOI (Zenodo and Software Heritage)

Every public repository is archived twice, so the design stays citable and retrievable if GitHub changes.

Zenodo (a citable DOI for each release):

1. Amish's Zenodo account is linked to GitHub. Before the first release, Amish switches the repository on in Zenodo (Account, GitHub). Only Amish changes Zenodo or GitHub settings.
2. Run `python .kit/archive.py zenodo`: it makes sure `CITATION.cff` names one license and adds the Zenodo DOI badge, which uses the GitHub repository ID and always points at the latest version. Zenodo reads its metadata (title, authors with ORCID, license, keywords) from `CITATION.cff`, and rejects the whole archive when that file lists several licenses.
3. Publish the GitHub release (section 14). Zenodo archives it within minutes and mints two DOIs: a version DOI for that release and a concept DOI that stands for all versions.
4. Check the Zenodo record: title, author and ORCID, license, keywords. If Zenodo shows "Citation metadata load failed", fix `CITATION.cff`, validate it with cffconvert and publish a new patch release (for example `v0.3.2`); a failed release is never re-used.
5. Run `python .kit/archive.py zenodo --doi <concept DOI>` and commit, so GitHub's "Cite this repository" and every future archive carry the concept DOI. Every later release gets its own version DOI automatically; the concept DOI never changes.

Software Heritage (permanent source archive):

1. After the repository is public, request a save at https://archive.softwareheritage.org/save/ (origin type git, the repository URL). Anonymous requests are limited to about ten an hour, so batches are spread out.
2. The Software Heritage badge on the README resolves once the save is accepted and ingested. Later pushes are picked up by its regular crawl.

OpenRatio repositories follow the same steps when Amish approves their release.

## 18. Prototype build plan (BLD) and the constructable design

### Two design states

A design moves through two states, recorded as `design_state` in `project.yaml`:

- **Concept**: the design shows what the product does and that it works on paper (TRL 2 and the calculations of TRL 3). Parts may be simplified shapes that have never been checked for how they are made or how they join.
- **Constructable**: every part can be made with the stated process and material, and every part fits and fastens to the parts next to it. Nothing is left as a shape that cannot be cut, cast, bent, printed, machined or bought.

A repo reaches TRL 3 only when its design is constructable and its build plan shows how. Writing the build plan is how the design is made constructable: when a part cannot be made or cannot fit as modelled, change the model so it can (Amish, 2026-09-30: "fix the design assumptions to match and be physically feasible"), keep what the concept does, and record every change in a decision record "Design for construction" (DDR) and in the plan. Changes that alter what the product does, its pitch or its safety case are proposed, not made.

### What the build plan is

`docs/05-build-plan.md` (`PRJ-BLD-001`) tells a capable maker how to build the first proof-of-concept prototype, in order, component by component, and shows it in pictures. It is written before anything is built, states "Plan, not yet built" under the title and never claims results. Building and testing to it is TRL 4 work.

### Writing rules

- **Plain English.** Say "the steel plate the jack stands on", not a model parameter or variable name. No code identifiers, function names, parameter names or file paths in the body of the plan. Give sizes as numbers with units ("a 62 mm hole, centred 100 mm up from the bottom edge"). The only place file names appear is the closing "Where the numbers come from" list.
- **Pictures first.** Every component and every assembly step has a picture. A reader should be able to build from the pictures, with the words explaining what the pictures cannot show (order, force, tolerance, checks).
- **By component, in build order.** Each component is made and checked before the step that needs it.
- **Cost is not the focus.** One line in the overview may state the parts cost from the BOM; there is no cost or time section.
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

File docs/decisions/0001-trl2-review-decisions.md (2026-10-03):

---
doc_id: ZBX-DDR-001
title: ZeerBox TRL 2 review decisions
project: ZeerBox
doc_type: Design decision record
version: "0.3"
status: Draft
date: '2026-10-02'
author: Amish Chadha
license: CERN-OHL-S-2.0
revisions:
- version: "0.1"
  date: '2026-09-25'
  author: Amish Chadha
  change: Record Amish's 2026-09-25 decisions on the TRL 2 review and the items that remain open
- version: "0.2"
  date: '2026-09-25'
  author: Amish Chadha
  change: Recommendations accepted by Amish (DDR-002). Items 11 to 13 decided; item 6 superseded by item 12
- version: "0.3"
  date: '2026-10-02'
  author: Amish Chadha
  change: Items 9 and 10 recorded as decided by Amish on 2026-10-02
---

# 0001: TRL 2 review decisions

- **Date:** 2026-09-25
- **Status:** accepted (items 1 to 8; items 11 to 13 accepted later the same day, see ZBX-DDR-002); items 9 and 10 decided by Amish on 2026-10-02 (ZBX-DEC-001)

## Context

The TRL 2 review note (`docs/REVIEW.md`, session 2026-09-25, /populate) listed ten items as "Proposed, awaiting Amish". On 2026-09-25 Amish reviewed the review points for every portfolio repo and wrote: "proceed with all of your recommendations across all batches. Make sure we don't proceed to TRL 4 on any of them." The same instruction approved cross-cutting SwapCell interface items, a pricing rule for shared SwapCell packs, and a rule that community designs pick co-design partners per area later.

This record lists what that instruction decides and what it leaves open because there was no recommendation to accept. TRL 4 is on hold by Amish's instruction.

## Options considered

The options for each item are in `docs/REVIEW.md` (TRL 2 section) and ZBX-PRC-001 v0.2. They are not repeated here.
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

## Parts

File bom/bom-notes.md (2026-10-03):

# BOM notes

All prices are indicative 2026 USD for parts bought in a regional town in sub-Saharan Africa. They are checked for arithmetic and against the TRL 3 sizing (ZBX-CAL-001) but not yet quoted by suppliers.

- Line numbers match the callouts in `media/exploded.png`. Line 14 (wiring and plumbing) has no callout, and line 15 (the strip footing, below ground) is shown in the build plan and the general arrangement, not in the concept views. Lines 15 to 18 were added to make the design constructable (ZBX-DDR-003).
- **Budget.** Decided by Amish, 2026-09-25 (ZBX-DDR-001 item 1): `budget_usd: 300` covers the cooling equipment kit. The structure is built from local materials and costed separately. Since 2026-10-01 the figure is a hypothetical value-engineering target, not a limit.
- **Cooling equipment kit** (items 6 to 11, 14 and 18). Value-engineering target: USD 300. Estimated cost of the constructable design: **USD 299** (USD 1 under the target); it rose from $270 by $22 for the panel mounting frames (line 18) and $10 for the pad frame, lining, bars and brackets, less $3 for the roof clamps they replace (ZBX-DDR-003). Before that, it rose by $27 from TRL 2 for the decided 150 W panel (+$20), a 20 A charge controller in place of 10 A (+$4) and 2.5 mm² PV cable (+$3), then by $10 for the 150 mm pad (decided by Amish, 2026-09-25, ZBX-DDR-002 item 11).
- **Structure** (items 1 to 5, 12, 15, 16 and 17), costed separately: **$574** in materials. It rose from $355 for the strip footing ($35), the roof beams and purlins ($70), the door lining, stops and fan box ($25), the framed ceiling (+$35), the full rack cut list (+$30 for two racks), lintels and wall ties (+$16) and post cap plates (+$8) (ZBX-DDR-003). Before that, it rose by $20 for 500 x 500 x 600 mm roof post footings, then fell by $5 when the wet sand cavity and wetting pipe gave way to dry rice husk with lime, mesh and a damp-proof course (ZBX-DDR-002 item 12). Mason's and carpenter's labor is not included.
- **Store total, crates excluded:** $873.
- **Crates** (item 13): $96 if bought; not included, since users normally own them.
- Specifications of 2026-10-02 (ZBX-DEC-001 items 6 to 8), no price change: line 9 names a clear-lid IP65 controller box with a 22 mm mode lamp in a hole in its top and a shield of six stacked round plates 46 mm across for the outside sensor; line 11 names a power box with a plain door.
- `python docs/04-calcs/sizing.py` reads this BOM and prints the group totals.

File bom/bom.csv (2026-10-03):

item | qty | spec | supplier | unit_cost_usd | make_buy | notes
1 Double brick walls, floor and lintels | 1 | About 2,000 fired bricks for two 115 mm leaves (outer 3.01 x 2.11 m, 2.1 m high) with a brick capping course over the cavity and a brick floor on a sand bed; about 0.6 m3 of cement-sand mortar; about 40 galvanized wire wall ties; four termite-treated hardwood lintels 115 x 100 mm (two 1.14 m over the door, two 0.94 m over the pad opening) | Local brickworks and hardware shop | 176.00 | make | Indicative: bricks about $0.06 each ($120), mortar about $40, lintels about $12, wall ties about $4; mason's labor not included. Lintels and ties priced from ZBX-DDR-003. Structure, costed separately from the kit (ZBX-DDR-001 item 1)
2 Dry rice husk cavity fill | 1 | About 1.3 m3 of dry rice husk in the 75 mm cavity (ZBX-CAL-001), mixed with hydrated lime against insects, on a plastic damp-proof course at the base, capped with a mortar course at the top and closed with 6 mm galvanized mesh at any opening | Local rice mill and hardware shop | 15.00 | buy | Indicative price (husk often free at the mill; lime, mesh and damp-proof sheet about $15). Decided in place of wet sand (ZBX-DDR-002, item 12); fall back to dry sand if no durable, pest-proof husk supply exists locally. Structure, costed separately
3 Insulated ceiling | 1 | Nine 50 x 100 mm joists 2.11 m long across the wall tops (two of them 360 mm apart to take the fan box), 25 x 25 mm cleats nailed along their sides, 50 mm straw board or foam board laid on the cleats with a plastic vapor sheet, 20 mm boards nailed over the joists; galvanized straps holding each joist end to the wall | Local timber yard | 70.00 | make | Indicative material cost (timber about $55, insulation, sheet and straps about $15); repriced for the framed ceiling of ZBX-DDR-003. Structure, costed separately
4 Shade roof: sheets, posts and footings | 1 | Corrugated galvanized steel sheets covering 3.9 x 3.0 m, screwed to the purlins with sealing-washer roofing screws; four 89 mm galvanized steel pipe posts with a welded 150 x 150 x 6 mm cap plate set to the roof slope, each cast 450 mm into a 500 x 500 x 600 mm concrete footing (uplift, ZBX-CAL-001) | Local hardware shop | 78.00 | make | Indicative: sheets and posts about $50, cap plates about $8, about 0.6 m3 of concrete for the footings about $20. Structure, costed separately
5 Insulated door with seal | 1 | Door leaf 794 x 1,792 x 50 mm (0.8 x 1.8 m nominal): timber frame, plywood skins, 50 mm insulation, three 100 mm butt hinges, inside release latch with no outside lock; opens outward | Local carpenter | 35.00 | make | Indicative material cost; must open from inside without a key. Lining and stops are line 16. Structure, costed separately
6 Cellulose pad and frame | 1 | 150 mm cellulose evaporative pad 0.6 x 0.5 m (0.3 m2); frame of 25 mm treated boards on two 25 x 50 mm wall battens; two 30 x 3 mm galvanized support bars and two retaining bars; 20 mm board lining for the wall opening; perforated 32 mm PVC drip header with end cap; galvanized return gutter 170 x 60 mm on two strip brackets, with a 32 mm outlet | Poultry or greenhouse equipment supplier; local carpenter | 50.00 | buy | Indicative price (pad about $30, frame, lining, bars and brackets about $10, header and gutter about $10); 150 mm decided in place of 100 mm (ZBX-DDR-002, item 11); frame details from ZBX-DDR-003
7 Sump drum and pump | 1 | 60 L covered plastic drum, 12 V DC submersible pump about 6 W and 2 m head, float switch, feed and return hoses | Local market and solar or pump supplier | 25.00 | buy | Indicative price
8 Exhaust fans | 2 | 250 mm 12 V DC axial fan, about 12 W and about 400 m3/h free air, with finger guards both faces and gravity shutter; mounted blowing upward on the ceiling fan box (ZBX-DDR-003) | Solar or electronics supplier | 15.00 | buy | Indicative price; delivered airflow about 290 m3/h each at about 16 Pa (ZBX-CAL-001, assumed linear fan curve); confirm with the fan's curve
9 Controller and sensors | 1 | Low-cost microcontroller board, two digital temperature and RH sensors (one in a radiation shield outside), MOSFET fan and pump drivers, memory card logger, 22 mm three-color mode lamp (ring flange 30 mm, in a 22 mm hole in the box top beside the door), shield of six stacked round plates 46 mm across on a stud for the outside sensor, clear-lid IP65 box about 200 x 250 x 80 mm for the controller (the lid is the window onto the board) | Electronics distributor | 30.00 | buy | Indicative price; unchanged by the 2026-10-02 specification (ZBX-DEC-001 items 6 to 8): a clear-lid IP65 box, a 22 mm panel lamp and six cut aluminium or plastic plates on a stud cost about what the earlier plain box, lamp and shield block did, so the $30 stands
10 Solar panel | 1 | 150 W monocrystalline, about 1,480 x 670 x 35 mm, Vmp about 18 V, Isc about 9 A, with frame mounting holes on the back flange | Regional solar distributor | 62.00 | buy | Indicative price; 150 W decided (ZBX-DDR-001 item 2); mounting frames are line 18
11 Power box | 1 | 20 A PWM solar charge controller (1.25 x Isc of the 150 W panel, ZBX-CAL-001), 12.8 V 12 Ah LiFePO4 battery with BMS rated for 10 A charge or more, 15 A fuse at the terminal, ventilated shaded box with a plain door (no window) | Regional solar distributor | 62.00 | buy | Indicative price (battery about $40, controller about $12); battery kept (ZBX-DDR-001 item 3); plain-door box as decided on 2026-10-02 (ZBX-DEC-001 item 6), no price change
12 Shelving racks | 2 | Timber rack 2.2 m long, 0.45 m deep, termite-treated: six 50 x 50 mm posts 1.75 m high, six 50 x 75 mm rails screwed to the inside faces of the posts, 45 slats 95 x 25 mm 350 mm long across the rails (shelf tops 0.30, 0.85 and 1.40 m above the floor); two 40 x 40 x 3 mm steel angle brackets fixing the end posts to the wall | Local carpenter | 35.00 | make | Indicative material cost per rack, repriced for the full cut list of ZBX-DDR-003. Structure, costed separately
13 Produce crates | 24 | Ventilated plastic crate about 500 x 350 x 300 mm, 20 kg of produce | User supplied | 4.00 | buy | Not included in the store cost; users normally own crates
14 Wiring and plumbing | 1 | 2.5 mm2 twin PV cable for the panel run and 1.5 mm2 twin cable for loads, IP65 connectors, cable glands, hose clips, fixings, dielectric grease | Local hardware shop | 18.00 | buy | Indicative price; no exploded-view callout
15 Wall strip footing | 1 | Concrete strip footing 450 mm wide and 250 mm deep under both leaves, top at ground level, about 1.0 m3, with a plastic damp-proof course on top under both leaves and the cavity | Local hardware shop | 35.00 | make | Indicative: cement, sand and stone; added by ZBX-DDR-003 (the calculation assumed it, the BOM did not price it). Structure, costed separately
16 Door lining, stops and fan box | 1 | 20 mm treated board lining for the door reveal (two jambs, a head), 20 x 40 mm stop beads with a rubber seal; fan box of 18 mm exterior plywood 310 x 640 mm, 150 mm deep, with an 18 mm top plate cut for two 250 mm fans; frame plugs and screws | Local timber yard; local carpenter | 25.00 | make | Indicative material cost; added by ZBX-DDR-003. Structure, costed separately
17 Roof beams and purlins | 1 | Two 75 x 150 mm beams 2.94 m long on the post cap plates (two M10 coach screws each end); five 50 x 150 mm purlins 3.8 m long on the beams with ten galvanized hurricane ties rated 2 kN or more | Local timber yard | 70.00 | make | Indicative: timber about $60, ties and screws about $10; added by ZBX-DDR-003, sized in ZBX-CAL-001 section 10. Structure, costed separately
18 Panel mounting frames | 2 | Per side: a 40 x 40 x 4 mm aluminium angle base rail 820 mm long screwed through the sheet crests into two purlins, a 670 mm top rail under the panel frame, and two 40 x 4 mm aluminium flat bar legs; M8 stainless bolts and sealing-washer roofing screws | Local aluminium or hardware shop | 11.00 | make | Indicative price per side; replaces the roof clamps of line 10 (ZBX-DDR-003)

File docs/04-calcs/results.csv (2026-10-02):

req | quantity | value | target | status
R1 | Crates on shelves; highest shelf | 24 crates (480 kg); top shelf 1.40 m | 20 or more crates; no lift above 1.6 m | Met
R2 | Mean store air below outside air, design point | 10.7 K (9.8 to 11.4 K); store 24.3 C | 8 K or more | Met
R3 | Mean store RH while cooling | 81 % (77 to 85 %) | 80 % or more | At risk
R4 | Humid-weather detection and mode change | Threshold 4 K wet-bulb depression; 30 C, 75 % RH gives 3.7 K and switches to hold; lamp shows mode | Detect under 4 K and switch, with indicator | Met (logic review; bench test later)
R5 | Guard and minimum ventilation | Pump off at 95 % RH for 60 min; hold mode about 8 ACH at about 2 W | Pump stop rule; 1 ACH or more with produce inside | Met (logic review; bench test later)
R6 | Tomato shelf life | No calculation basis; ZECC data (about 1.8 times) come from a cooler, more humid chamber | 1.5 times ambient or more | Not verifiable at TRL 3
R7 | Design-day energy from one PV panel | 372 Wh/day needed; 150 W panel gives 525 Wh/day (41 % margin) | 10 h cooling plus 2 h evening, no grid | Met
R8 | Water per design day; sump capacity | 36 L/day (pad 32, cavity 0, bleed 4); sump 60 L for 36 L of pad use | 70 L or less; sump at least one day | Met
R9 | 12 V DC, fused, guarded, door opens from inside | 12.8 V system, 15 A terminal fuse; guards both faces; inside release (design review) | 12 V DC, fused, guarded, inside release | Met (design review)
R10 | Local build; 30 min part swaps | Masonry, timber and generic 12 V parts; swap times and parts survey need the partner | Local trades; swap in 30 min or less | Not verifiable at TRL 3
R11 | Durability: structure 10 years, pad and fans 3 years | Wall bearing 16 kPa; post footings 1.8 x uplift at 30 m/s; pad and fan life from supplier data not yet available | 10 years structure; 3 years pad, fans, pump | Not verifiable at TRL 3
R12 | Cooling equipment kit cost against the value-engineering target (structure costed separately) | Kit $299; structure $574 (separate); crates $96 (user supplied) | Kit $300 value-engineering target | Under the target by $1

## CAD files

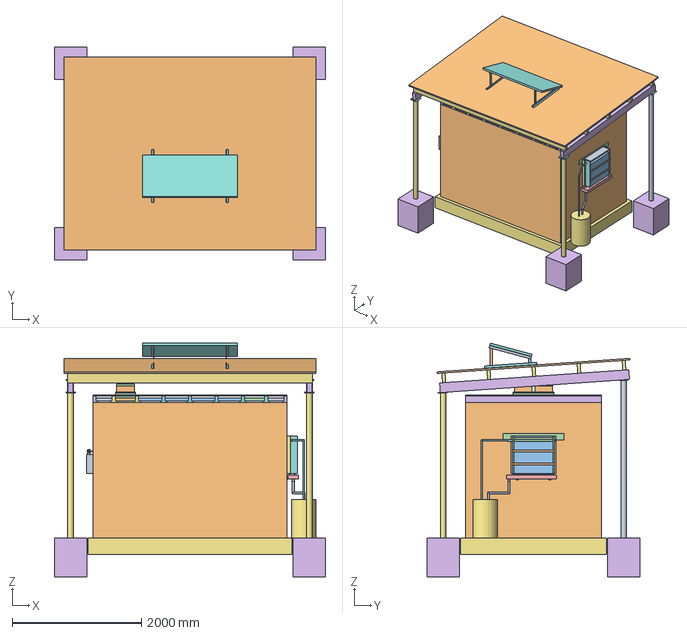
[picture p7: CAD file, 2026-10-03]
cad/step/zeerbox-assembly.step
4200.0 x 3300.0 x 3623.6 mm

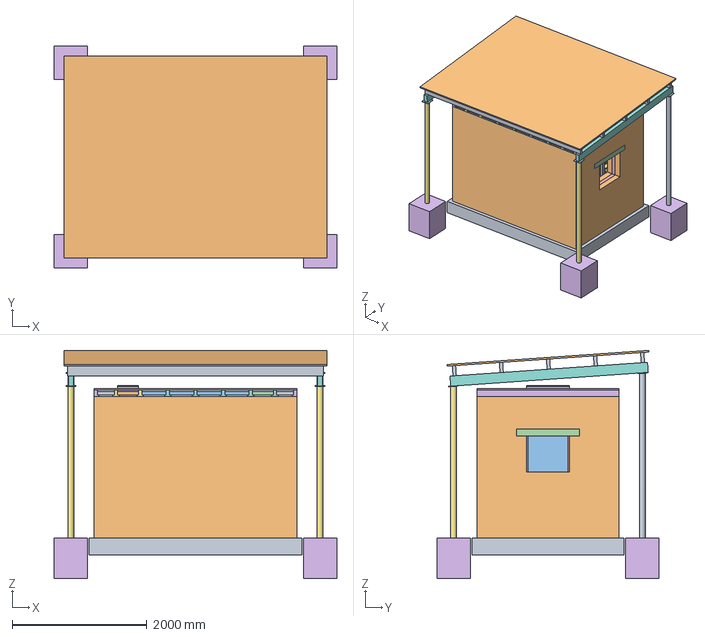
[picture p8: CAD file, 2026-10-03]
cad/step/zeerbox-structure.step
4200.0 x 3300.0 x 3387.1 mm

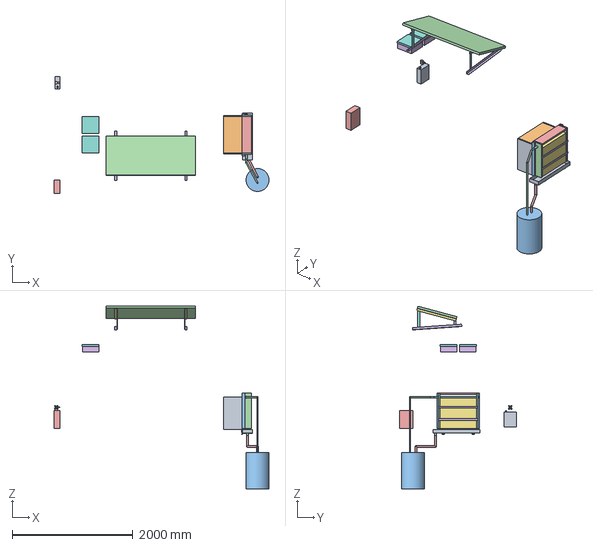
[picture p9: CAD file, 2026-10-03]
cad/step/zeerbox-cooling-kit.step
3560.0 x 1930.0 x 3023.6 mm

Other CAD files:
cad/stl/zeerbox-assembly.stl
cad/stl/zeerbox-cooling-kit.stl
cad/stl/zeerbox-structure.stl

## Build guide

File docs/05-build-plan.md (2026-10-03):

---
doc_id: ZBX-BLD-001
title: ZeerBox prototype build plan
project: ZeerBox
doc_type: Build plan
version: "0.2"
status: Draft
date: '2026-10-02'
author: Amish Chadha
license: CERN-OHL-S-2.0
revisions:
  - version: "0.1"
    date: '2026-10-02'
    author: Amish Chadha
    change: First build plan; design made constructable (ZBX-DDR-003)
  - version: "0.2"
    date: '2026-10-02'
    author: Amish Chadha
    change: Controller box with its mode lamp and the plate shield for the outside sensor; power box with a plain door; pictures redrawn
---

# ZeerBox prototype build plan

**Plan, not yet built.** How to build the first proof-of-concept prototype, component by component. Building and testing to it is TRL 4 work. Decisions still to be made are kept in the design decisions register ([docs/06-design-decisions.md](06-design-decisions.md)), not here.

## 1. What you are building

Figure 1. Every component, pulled apart and numbered in build order

*Figure 1. Every component pulled apart and numbered in build order. The crates are the users' own and are not shown.*

The prototype is one walk-in store, 2.4 x 1.5 x 2.0 m inside, on a patch of level, firm ground about 4.5 x 3.5 m. It has double brick walls around a dry rice husk cavity, a framed and insulated ceiling, a corrugated shade roof on four steel posts, a 150 mm wetted pad in the back wall, two 12 V fans in a ceiling fan box at the door end, a sump drum and pump, a 150 W solar panel on the roof, a controller and a power box beside the door, and two timber racks for 24 crates. Figure 1 shows the 28 components in the order they are made or fitted. Most are made on site: concrete is cast, bricks are laid, and timber, plywood, aluminium angle and galvanized sheet are sawn, drilled, bent and screwed. The pad, fans, pump, drum, panel, battery, charge controller and controller parts are bought and fitted. A local mason builds the footings and walls and a carpenter the timber work; the metal parts need a drill, a hacksaw and, for the post caps, a welder. The parts cost about $873 from the bill of materials, crates excluded.

> **Safety:** This is a building that people walk into and stand under. About 7 t of brickwork and a roof that the wind tries to lift must be built by a competent mason, and the roof must be screwed and tied down before the first windy day. The door must open from inside at all times, with no outside lock. The store holds a 154 Wh lithium iron phosphate battery, fans that can catch fingers and a drum of warm water that can grow *Legionella*: keep the battery fuse out until section 6 says otherwise, guard the fans on both faces, and keep the drum covered. Rice husk burns: no flames or hot work near the walls once the cavity is filled. Weld the post caps before the posts go in, away from the site.

## 2. What changed to make it buildable

The concept showed what the store does; some of its parts could not be built as drawn. Each change below keeps what the store does and its calculated cooling, and all of them are recorded in decision record ZBX-DDR-003, open for Amish's review.

*Table 1. Changes from the concept.*

| Component | The concept had | The buildable design has | Why |
| --- | --- | --- | --- |
| Exhaust fans | Two round holes in the front wall beside the door | One plywood fan box in the ceiling at the door end, over the aisle; the fans blow up into the shaded roof space (Figures 16 and 17) | The wall holes left 50 mm of brick beside the door and the corners, too narrow to build or to carry a lintel |
| Shade roof | A sheet resting on four post tops | Two beams on welded post caps, five purlins, sheets screwed to the purlins (Figures 4 and 18 to 20) | A 3.9 x 3.0 m sheet cannot span between four posts; 150 mm deep purlins carry the wind uplift |
| Foundations | Walls on bare ground | A concrete strip footing 450 x 250 mm under both leaves (Figure 2) | The calculation already assumed it |
| Door and pad openings | Holes straight through the cavity wall | A hardwood lintel over each leaf, a board lining on every reveal, a door lining with stop beads and hinges, a 74 mm door (Figures 7, 8 and 10 to 12) | Something must carry the brick above, close the cavity at the reveal and hang the door |
| Ceiling | A solid slab | Joists, cleats, insulation and boards, the same 120 mm thick (Figures 13 to 15) | A slab of boards and straw needs a structure |
| Racks | Posts passing through the shelves | Rails on the inside faces of the posts, slats across them, wall brackets (Figures 28 and 29) | A shelf cannot occupy the same space as its post |
| Pad | A frame ring and a floating header | A board frame on wall battens with support and retaining bars, the header lying on the pad, a gutter on brackets (Figures 23 to 27) | Each part needs something to sit on and something to hold it |
| Solar panel | Floating 150 mm above the roof | Two aluminium frames screwed through the sheet into the purlins (Figures 21 and 22) | A fixing that reaches the structure |
| Sump drum | Half outside the roof edge | Fully under the roof | Shaded water stays cooler and cleaner |

## 3. Making the components

Make and check each component before the assembly step that needs it. Sizes are in millimetres. "Left" and "right" are as seen standing outside the door, looking at it; the door is at the front end and the pad at the back end. The roof slopes down to the right. Heights are above the finished ground at the walls. Site tolerance is 5 mm for masonry and 2 mm for joinery unless a step says otherwise; drawings do not carry tolerances before TRL 4.

### 3.1 Wall strip footing

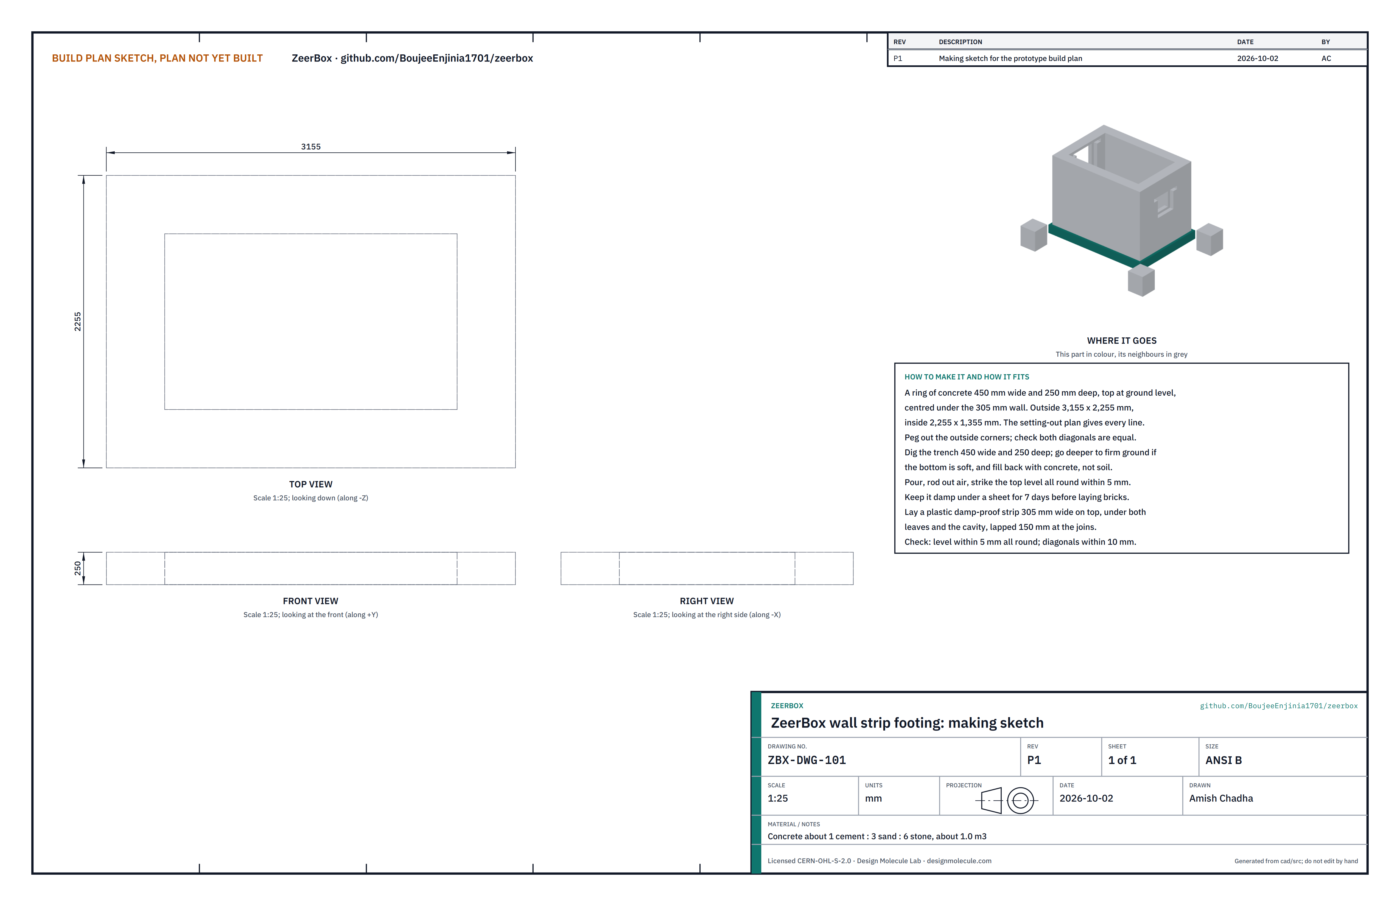
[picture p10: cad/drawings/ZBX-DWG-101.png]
Figure 2. Making sketch of the wall strip footing


*Figure 2. Wall strip footing making sketch (ZBX-DWG-101).*

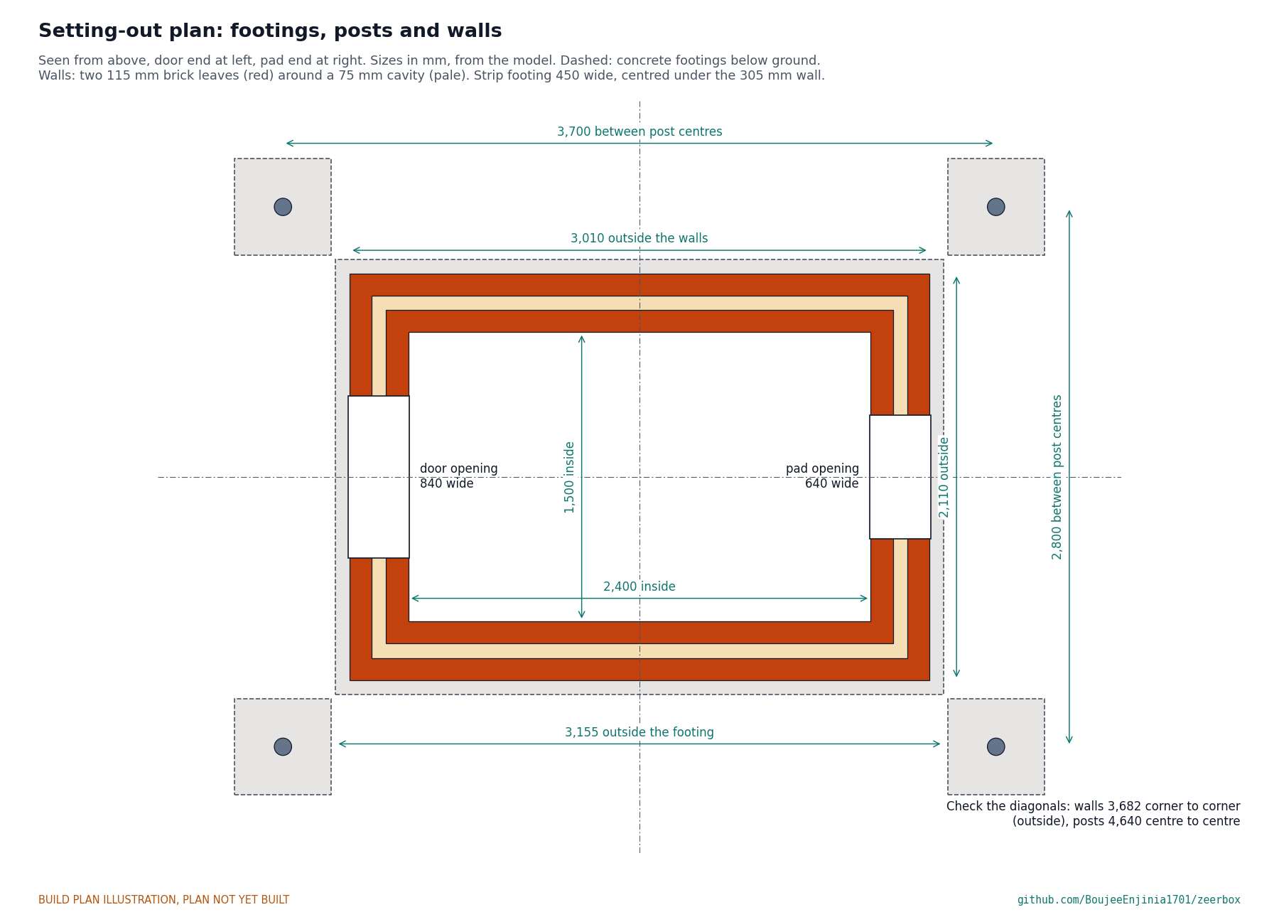
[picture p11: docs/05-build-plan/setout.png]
Figure 3. Setting-out plan


*Figure 3. Setting-out plan: footings, posts, walls and openings.*

**What it is and what it is made from.** A rectangular ring of concrete that the two brick leaves stand on. About 1 m³ of concrete, about 1 part cement to 3 sand to 6 stone, with a plastic damp-proof strip on top.

**How to make it.**

1. Clear and level the site. Peg out the outside of the walls, 3,010 x 2,110 mm, from Figure 3; check that both diagonals are equal (3,682 mm).
2. Mark the trench 450 mm wide, centred on the wall line: 3,155 x 2,255 mm outside, 2,255 x 1,355 mm inside.
3. Dig 250 mm deep. Where the bottom is soft, dig to firm ground and fill back with concrete, not soil.
4. Pour, rod out the air, and strike the top level all round with the ground.
5. Keep it damp under a sheet for 7 days.
6. Lay a plastic damp-proof strip 305 mm wide on top, under both leaves and the cavity, lapped 150 mm at every join.

**How it fits the parts next to it.** Both brick leaves and the husk fill stand on the damp-proof strip, centred on the footing (Figure 5). The post footings sit 23 mm clear of its outside corners (Figure 3).

**Check before moving on.** Top level within 5 mm all round; diagonals within 10 mm.

### 3.2 Roof posts and their footings (make 4)

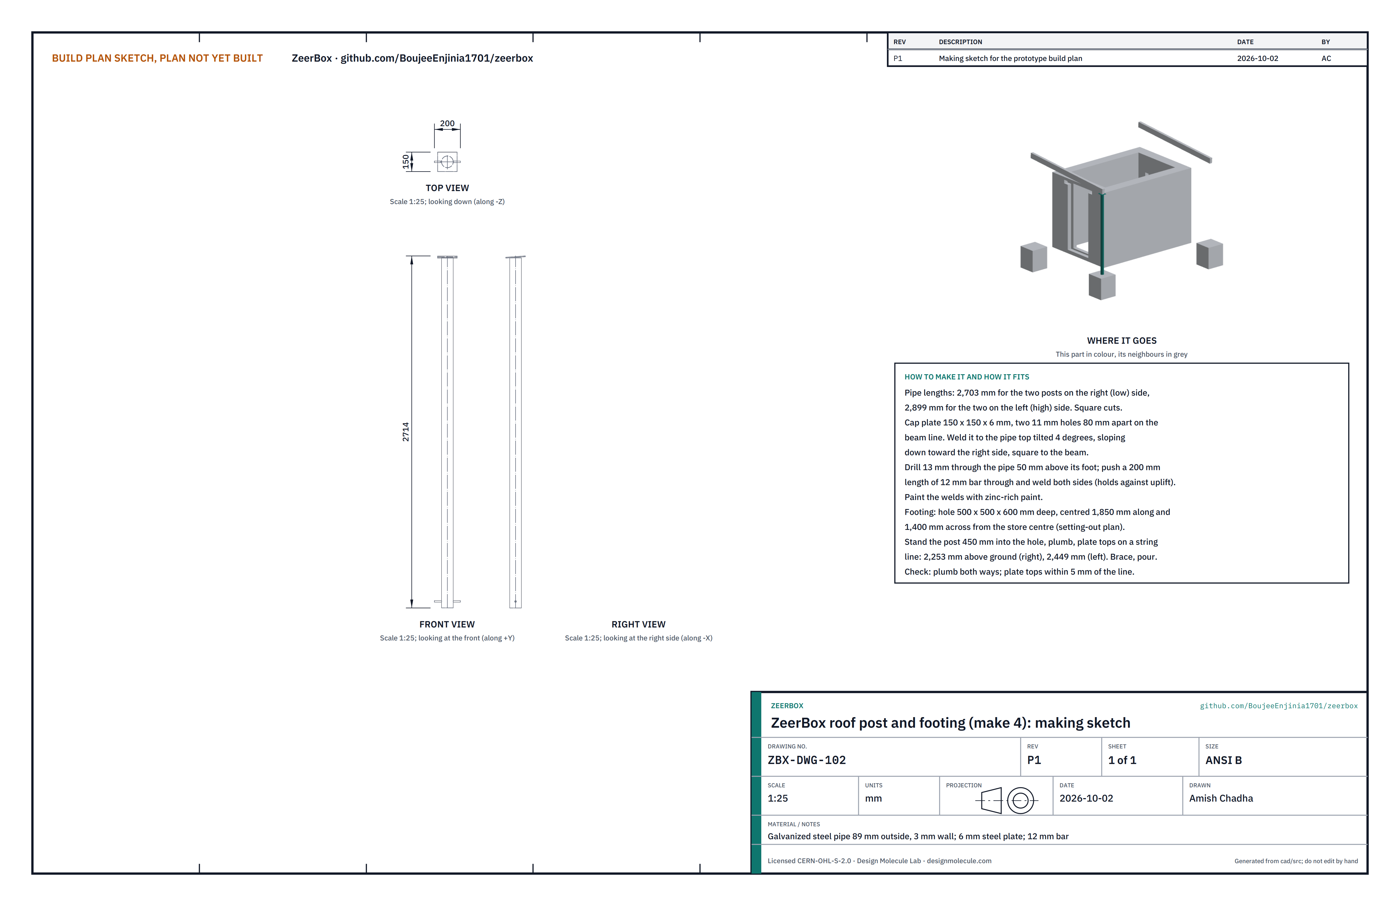
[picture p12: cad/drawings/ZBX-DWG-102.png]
Figure 4. Making sketch of the roof post


*Figure 4. Roof post making sketch (ZBX-DWG-102).*

**What it is and what it is made from.** A galvanized steel pipe, 89 mm outside and 3 mm wall, with a 150 x 150 x 6 mm steel cap plate welded on top and a 12 mm bar through its foot, cast 450 mm into a 500 x 500 x 600 mm concrete footing.

**How to make it.**

1. Cut two pipes 2,703 mm long for the right (low) side and two 2,899 mm long for the left (high) side, square.
2. Drill each cap plate with two 11 mm holes 80 mm apart on its centre line.
3. Weld the plate to the pipe top, tilted 4° so it slopes down toward the right side, with the holes running across the store.
4. Drill a 13 mm hole through each pipe 50 mm above its foot, push through a 200 mm length of 12 mm bar and weld both sides. This bar holds the post down against wind uplift.
5. Paint every weld with zinc-rich paint.
6. Dig the four holes 500 x 500 x 600 mm deep, centred 1,850 mm along and 1,400 mm across from the store's centre (Figure 3; 3,700 mm and 2,800 mm between centres, 4,640 mm on the diagonals).

**How it fits the parts next to it.** Each post stands 450 mm deep in its hole, plumb, with its cap plate top on a string line: 2,253 mm above ground on the right side and 2,449 mm on the left. The roof beams sit on the plates (Figure 19).

**Check before moving on.** Each post plumb both ways; plate tops within 5 mm of the string line.

### 3.3 Double brick walls and the rice husk fill

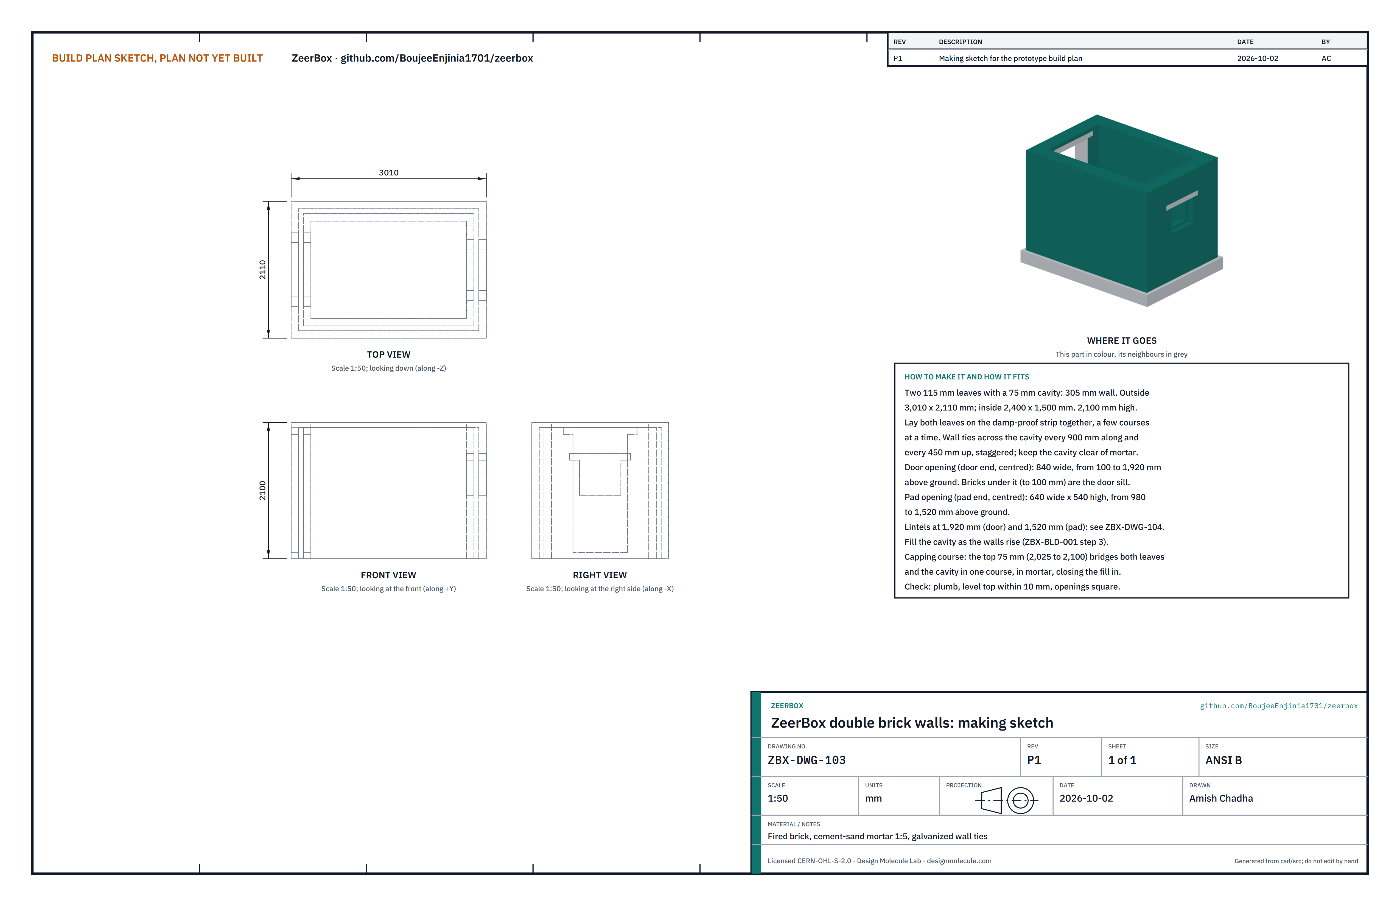
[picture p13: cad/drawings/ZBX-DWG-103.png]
Figure 5. Making sketch of the walls


*Figure 5. Double brick walls making sketch (ZBX-DWG-103).*

**What it is and what it is made from.** Two leaves of fired brick, each 115 mm thick, with a 75 mm cavity filled with dry rice husk: a 305 mm wall, 2,100 mm high. Outside 3,010 x 2,110 mm, inside 2,400 x 1,500 mm. Cement-sand mortar 1:5 and galvanized wire wall ties. The husk is mixed with hydrated lime against insects.

**How to make it.**

1. Lay both leaves together on the damp-proof strip, a few courses at a time.
2. Bed a wall tie across the cavity every 900 mm along and every 450 mm up, staggered. Keep mortar out of the cavity; a board lifted along it as you go catches droppings.
3. Leave the door opening in the front wall, centred: 840 mm wide, from 100 to 1,920 mm above ground. The bricks under it, up to 100 mm, are the door sill.
4. Leave the pad opening in the back wall, centred: 640 mm wide and 540 mm high, from 980 to 1,520 mm above ground.
5. Every six courses, pour husk and lime into the cavity and settle it by tapping the wall, not by ramming.
6. Stop at 1,520 mm for the pad lintels (section 3.4, step 4), then build on to 1,920 mm for the door lintels (step 5).
7. Finish with a capping course from 2,025 to 2,100 mm that bridges both leaves and the cavity in one course, closing the husk in.

**How it fits the parts next to it.**

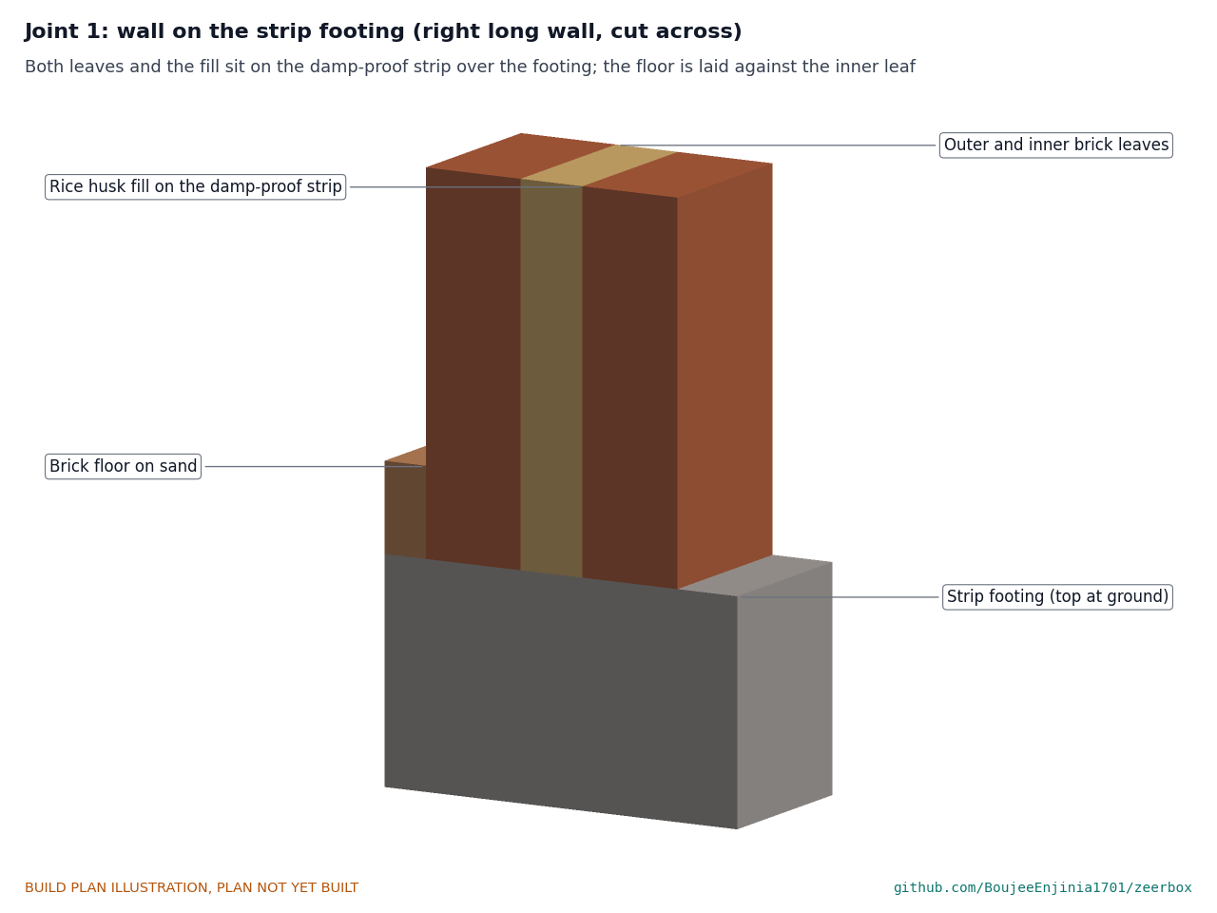
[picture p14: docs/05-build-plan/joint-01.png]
Figure 6. Joint 1: wall on the strip footing


*Figure 6. Both leaves and the fill sit on the damp-proof strip over the footing; the floor is laid against the inner leaf.*

**Check before moving on.** Walls plumb; top level within 10 mm; openings square and to size; no mortar bridging the cavity.

### 3.4 Lintels (make 4)

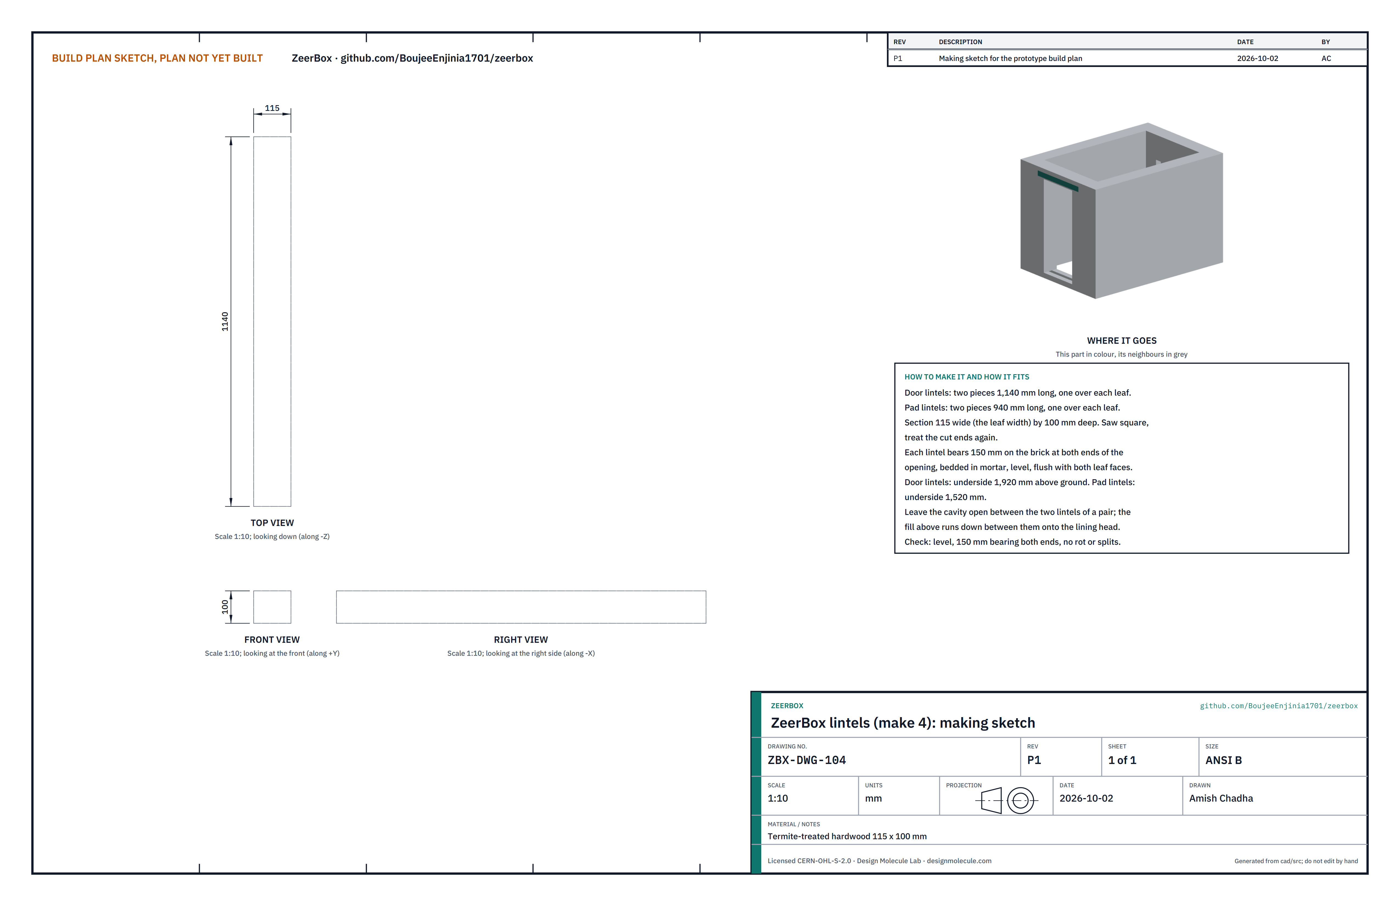
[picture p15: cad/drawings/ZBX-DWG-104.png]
Figure 7. Making sketch of the lintels


*Figure 7. Lintels making sketch (ZBX-DWG-104).*

**What it is and what it is made from.** One beam over each leaf at each opening. Termite-treated hardwood, 115 mm wide (the leaf width) and 100 mm deep.

**How to make it.**

1. Cut two lengths of 1,140 mm for the door and two of 940 mm for the pad.
2. Treat the cut ends again.

**How it fits the parts next to it.**

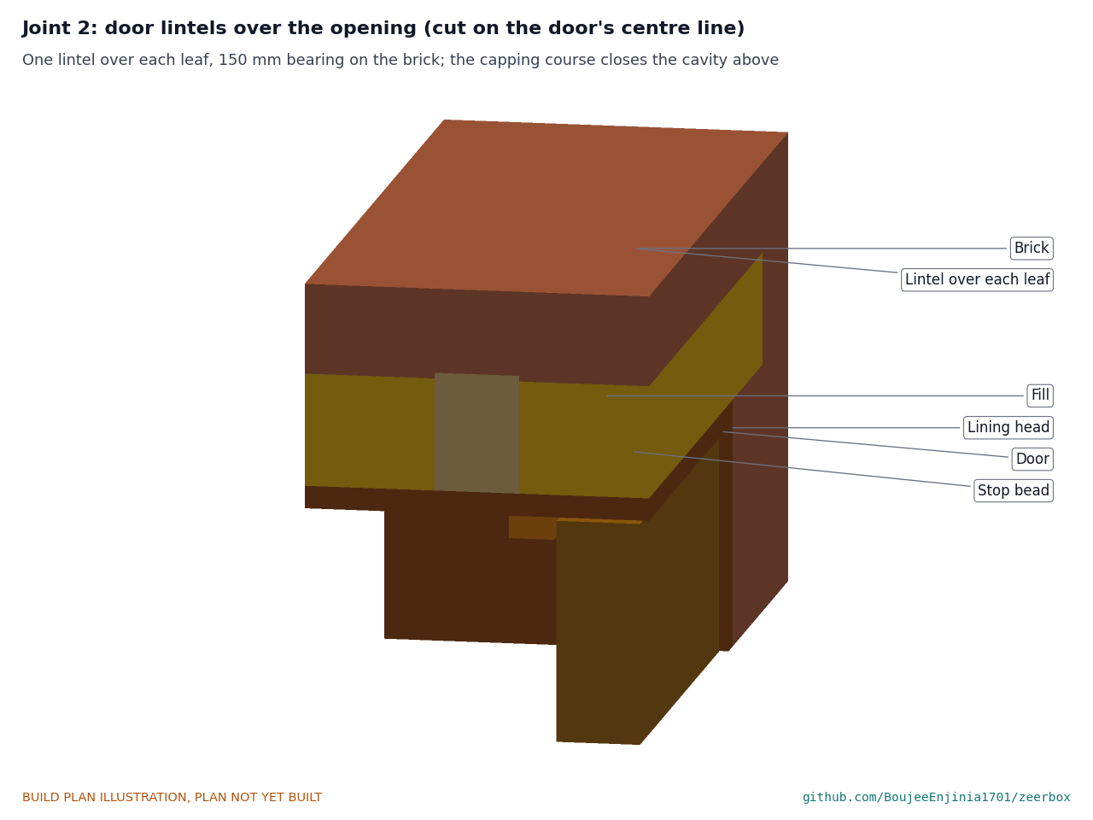
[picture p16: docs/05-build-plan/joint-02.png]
Figure 8. Joint 2: door lintels


*Figure 8. One lintel over each leaf, flush with both leaf faces; the cavity stays open between them and the capping course closes it above.*

Each lintel bears 150 mm on the brick at both ends, bedded level in mortar: undersides at 1,520 mm for the pad and 1,920 mm for the door. The husk above an opening runs down between the two lintels onto the lining head.

**Check before moving on.** Level; 150 mm of bearing at both ends; no rot or splits.

### 3.5 Brick floor

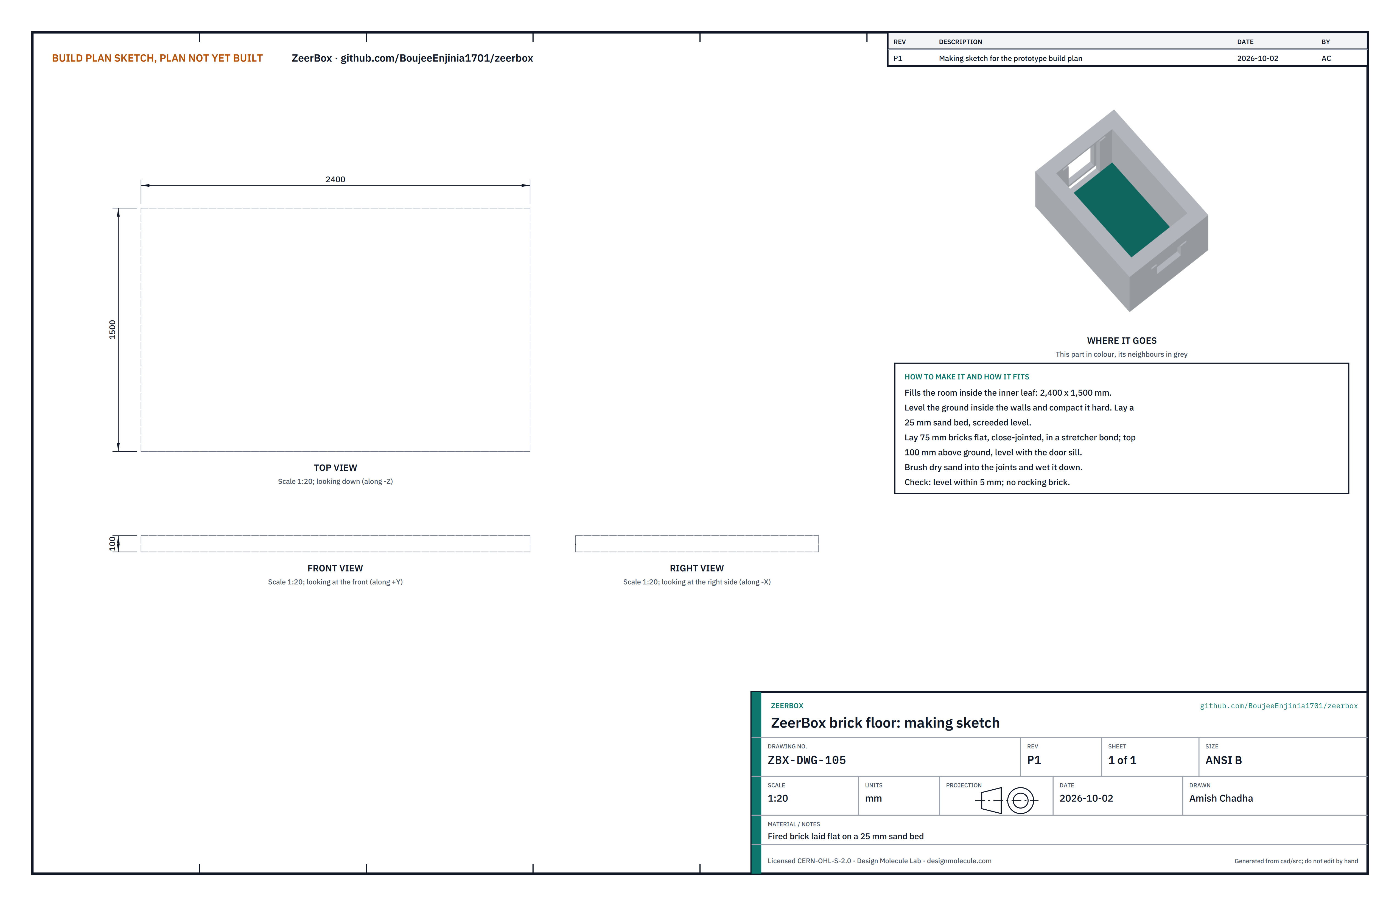
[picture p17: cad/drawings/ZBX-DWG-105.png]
Figure 9. Making sketch of the floor


*Figure 9. Brick floor making sketch (ZBX-DWG-105).*

**What it is and what it is made from.** The floor of the room, 2,400 x 1,500 mm, of fired bricks laid flat on a 25 mm sand bed.

**How to make it.**

1. Level and compact the ground inside the walls.
2. Screed a 25 mm sand bed level.
3. Lay the bricks flat and close-jointed in a stretcher bond, top 100 mm above ground, level with the door sill.
4. Brush dry sand into the joints and wet it down.

**How it fits the parts next to it.** The floor fills the room against the inner leaf on all four sides; the racks stand on it.

**Check before moving on.** Level within 5 mm; no brick rocks.

### 3.6 Door lining and stop beads

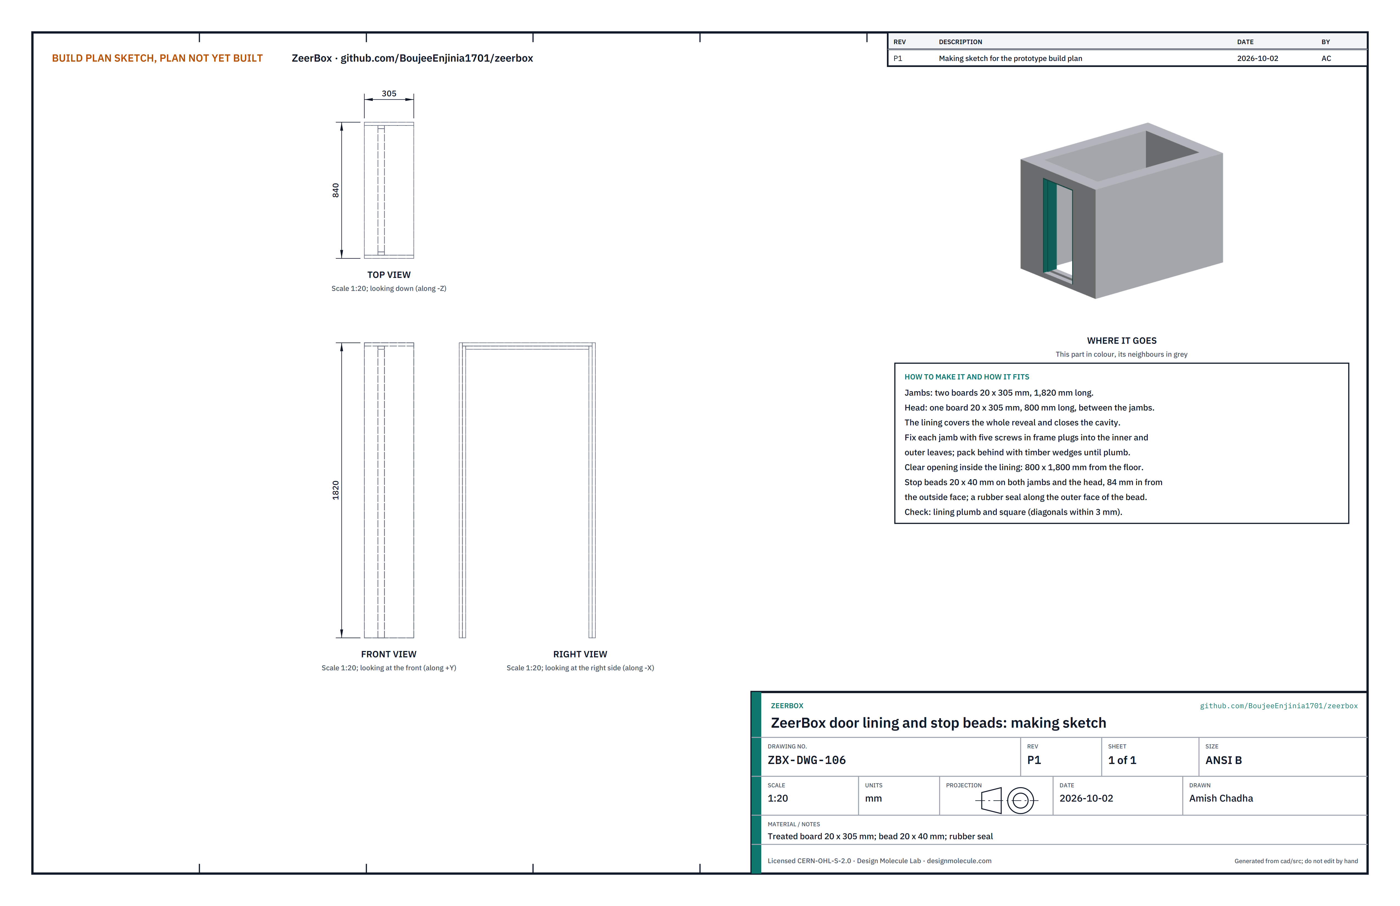
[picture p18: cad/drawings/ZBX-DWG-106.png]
Figure 10. Making sketch of the door lining


*Figure 10. Door lining and stop beads making sketch (ZBX-DWG-106).*

**What it is and what it is made from.** Three treated boards, 20 x 305 mm, that line the door opening and close the cavity, with 20 x 40 mm stop beads and a rubber seal.

**How to make it.**

1. Cut two jambs 1,820 mm long and a head 800 mm long.
2. Cut stop beads to fit both jambs and the head.

**How it fits the parts next to it.**

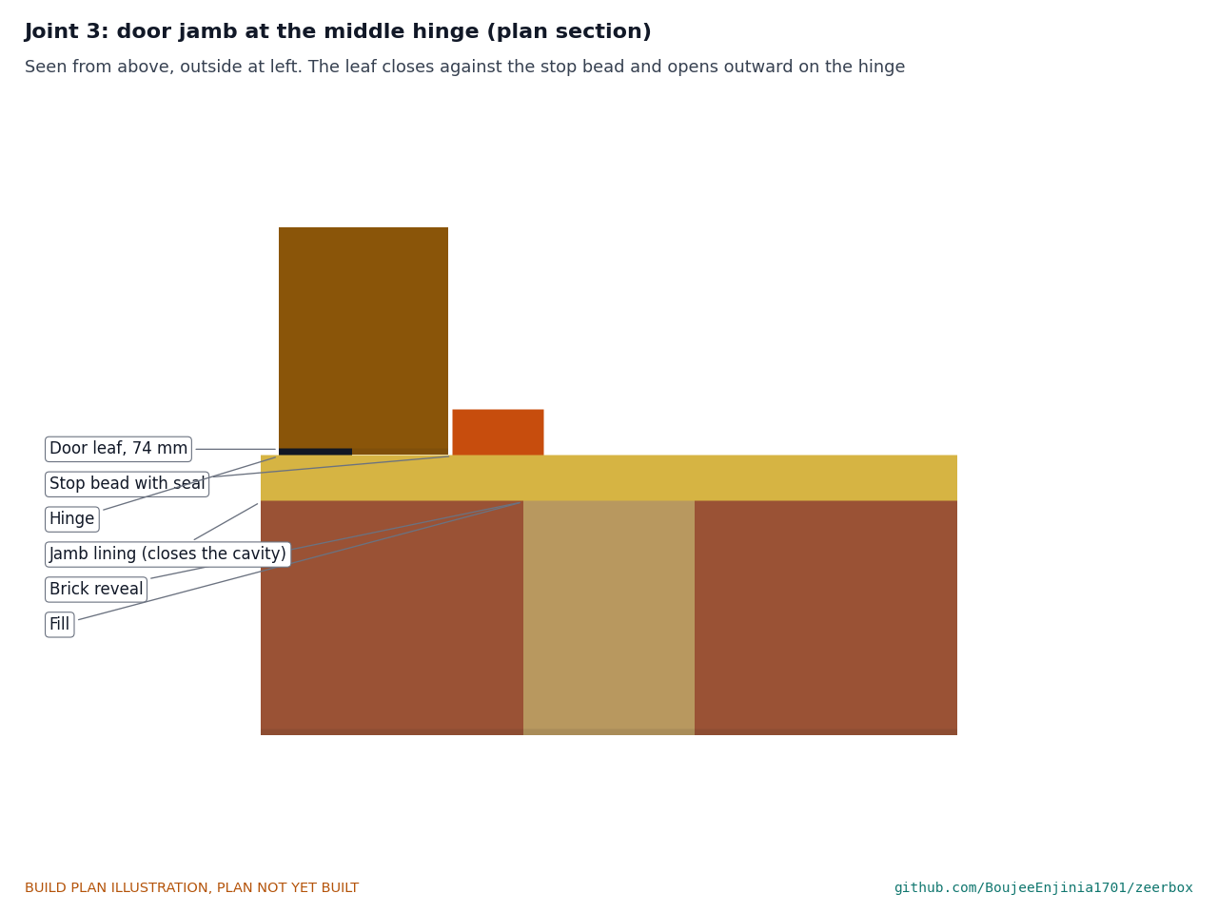
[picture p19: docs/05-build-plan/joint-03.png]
Figure 11. Joint 3: the door jamb


*Figure 11. Plan section through the middle hinge: lining, stop bead with seal, door leaf and hinge.*

The jambs stand on the sill and the head sits between them, under the lintels. Fix each jamb with five screws in frame plugs into both leaves, packing behind with timber wedges until plumb. The clear opening inside the lining is 800 x 1,800 mm. The stop beads are screwed to the lining 84 mm in from the outside face, with the seal on their outer face.

**Check before moving on.** Lining plumb and square, diagonals within 3 mm.

### 3.7 Door

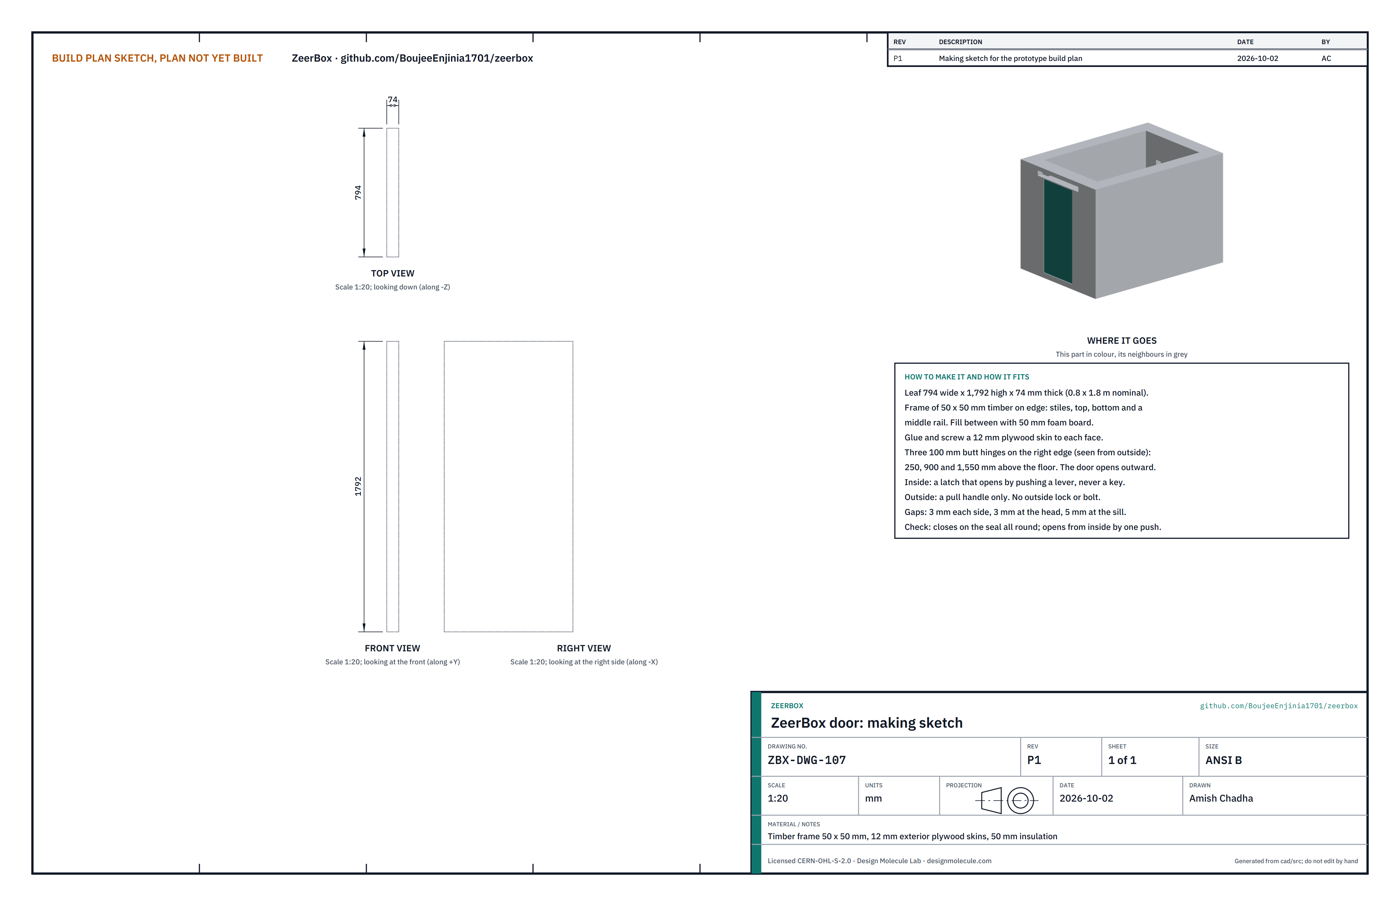
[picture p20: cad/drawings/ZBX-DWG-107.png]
Figure 12. Making sketch of the door


*Figure 12. Door making sketch (ZBX-DWG-107).*

**What it is and what it is made from.** An insulated leaf 794 x 1,792 x 74 mm: a frame of 50 x 50 mm timber, 50 mm foam board between, a 12 mm exterior plywood skin on each face.

**How to make it.**

1. Make the frame: two stiles, a top, a bottom and a middle rail, glued and screwed.
2. Cut and fit the foam between the frame members.
3. Glue and screw a plywood skin to each face.
4. Fit three 100 mm butt hinges on the right edge, 250, 900 and 1,550 mm above the floor.
5. Fit a latch that opens from inside by pushing a lever, and a pull handle outside. Fit no outside lock or bolt.

**How it fits the parts next to it.** The leaf hangs in the lining, hinged on the right, and closes against the stop beads from outside; it opens outward (Figure 11). Gaps are 3 mm at the sides and head and 5 mm at the sill.

**Check before moving on.** The door closes on the seal all round and opens from inside with one push.

### 3.8 Ceiling joists (make 9)

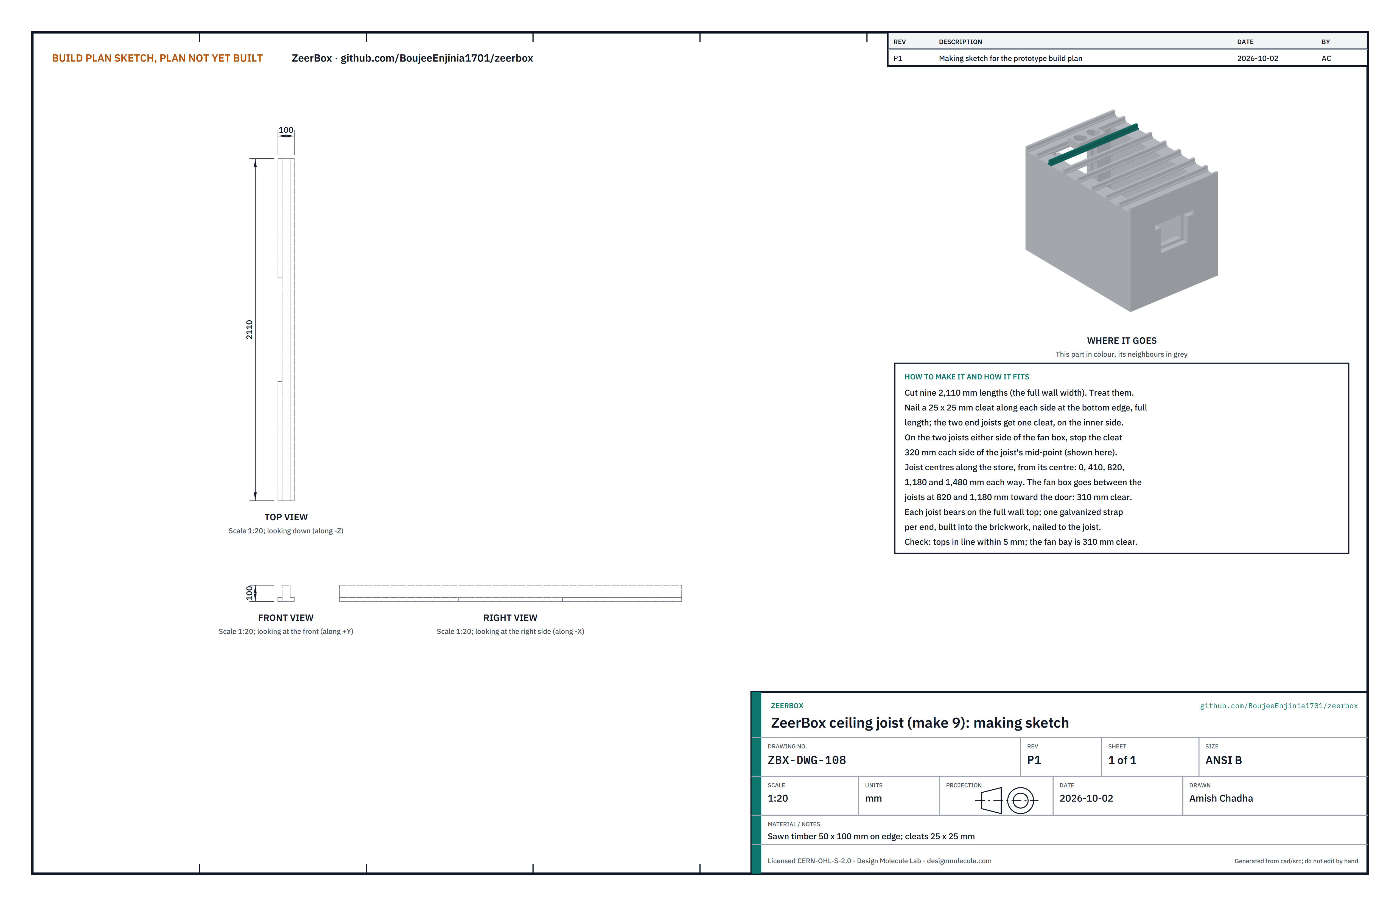
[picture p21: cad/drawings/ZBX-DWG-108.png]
Figure 13. Making sketch of the ceiling joist


*Figure 13. Ceiling joist making sketch (ZBX-DWG-108).*

**What it is and what it is made from.** Sawn, treated timber 50 x 100 mm on edge, 2,110 mm long, with a 25 x 25 mm cleat along each side at the bottom edge.

**How to make it.**

1. Cut nine joists 2,110 mm long and treat them.
2. Nail a cleat along each side at the bottom edge, full length. The two end joists get one cleat, on the inner side.
3. On the two joists either side of the fan box, stop the cleat on the fan side 320 mm each side of the joist's mid-point.

**How it fits the parts next to it.**

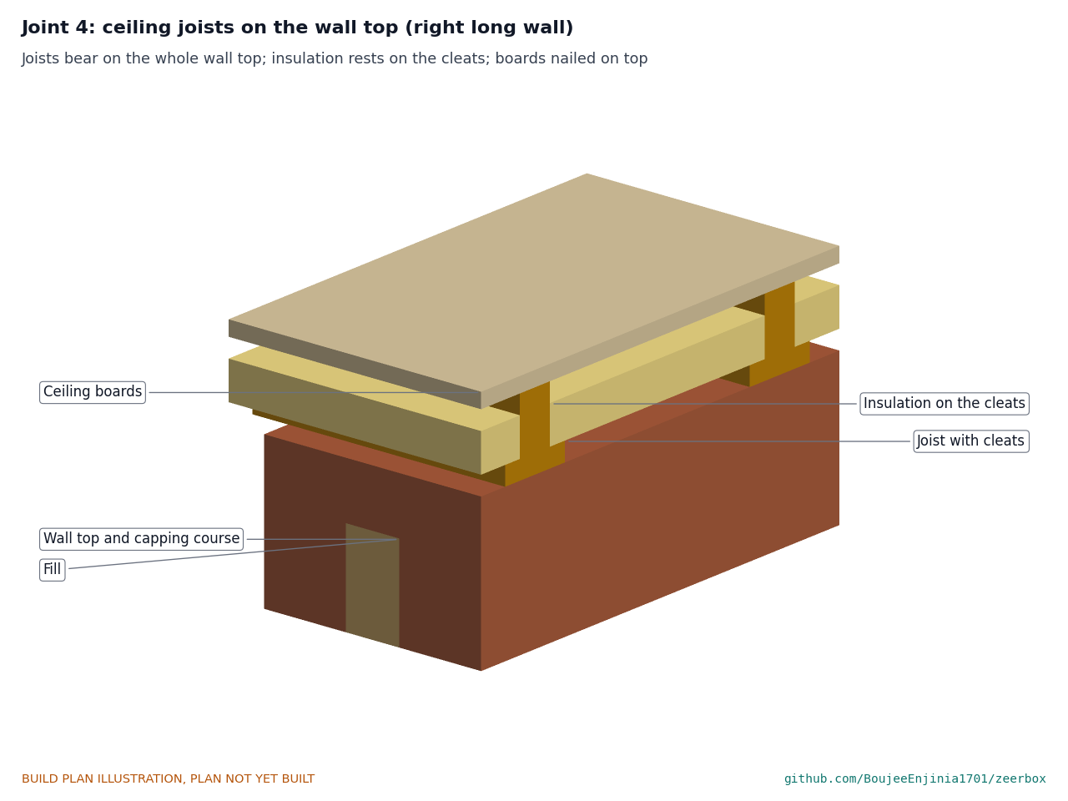
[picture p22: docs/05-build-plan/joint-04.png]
Figure 14. Joint 4: joists on the wall top


*Figure 14. Joists bear on the whole wall top; insulation rests on the cleats; boards are nailed on top.*

The joists lie across the store on the wall tops, their centres 0, 410, 820, 1,180 and 1,480 mm each way from the store's centre. The fan bay is between the joists at 820 and 1,180 mm toward the door: 310 mm clear. One galvanized strap per joist end, built into the brickwork, is nailed to the joist.

**Check before moving on.** Tops in line within 5 mm; the fan bay is 310 mm clear.

### 3.9 Ceiling insulation and boards

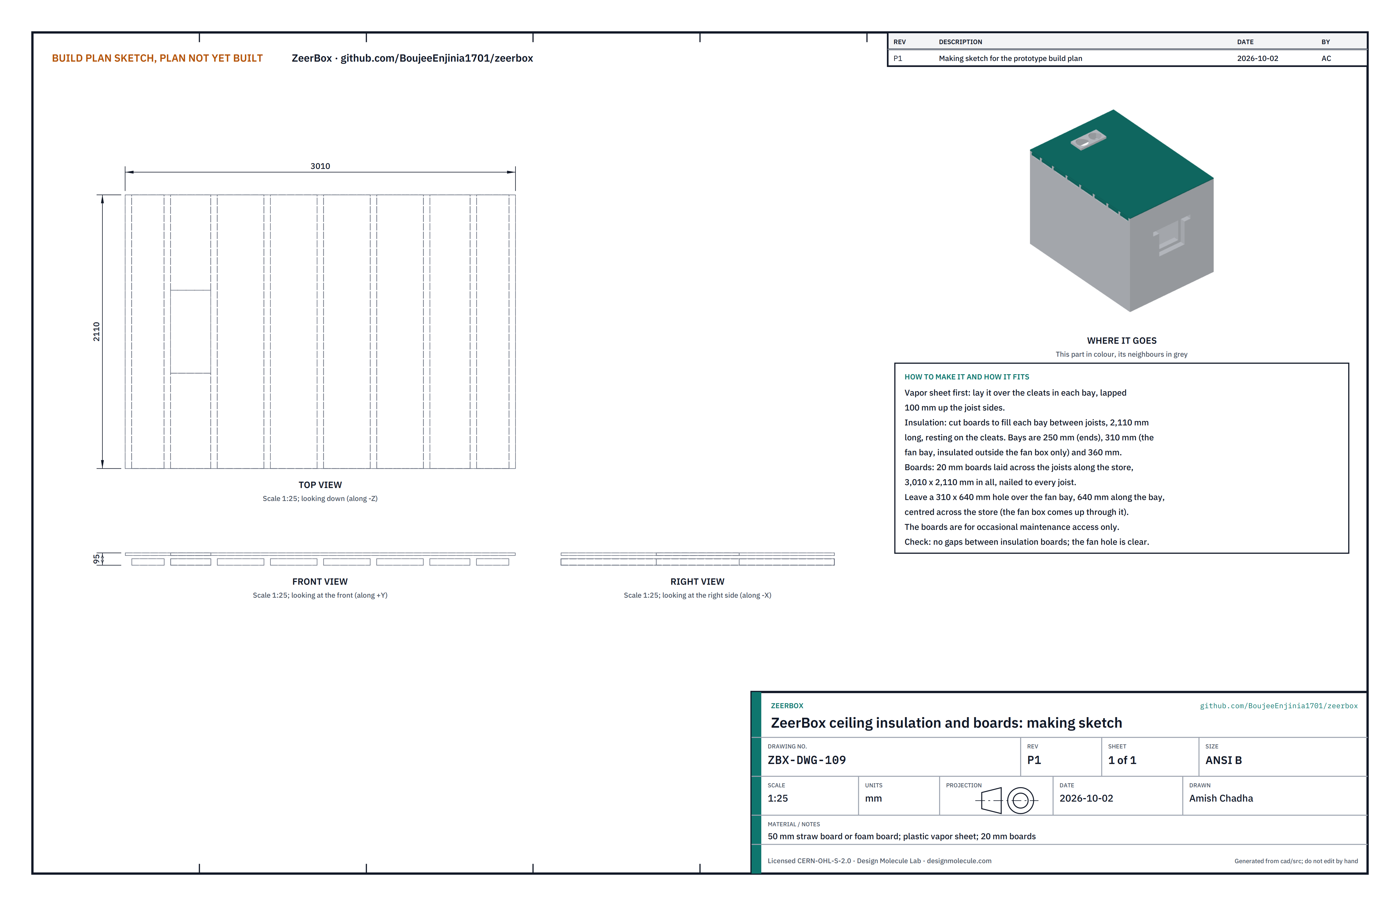
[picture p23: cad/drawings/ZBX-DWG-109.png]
Figure 15. Making sketch of the insulation and boards


*Figure 15. Ceiling insulation and boards making sketch (ZBX-DWG-109).*

**What it is and what it is made from.** A plastic vapor sheet, 50 mm straw board or foam board and 20 mm boards.

**How to make it.**

1. Cut the insulation to fill each bay between joists, 2,110 mm long: bays are 250 mm at the ends, 310 mm in the fan bay and 360 mm elsewhere.
2. Cut the boards to cover 3,010 x 2,110 mm, leaving a 310 x 640 mm hole over the fan bay, centred across the store.

**How it fits the parts next to it.** The vapor sheet lies over the cleats in each bay, lapped 100 mm up the joist sides; the insulation rests on it; the boards are nailed to every joist (Figure 14). In the fan bay the insulation fills only the length outside the fan box. The boards are for occasional maintenance access only.

**Check before moving on.** No gaps between insulation boards; the fan hole is clear.

### 3.10 Fan box

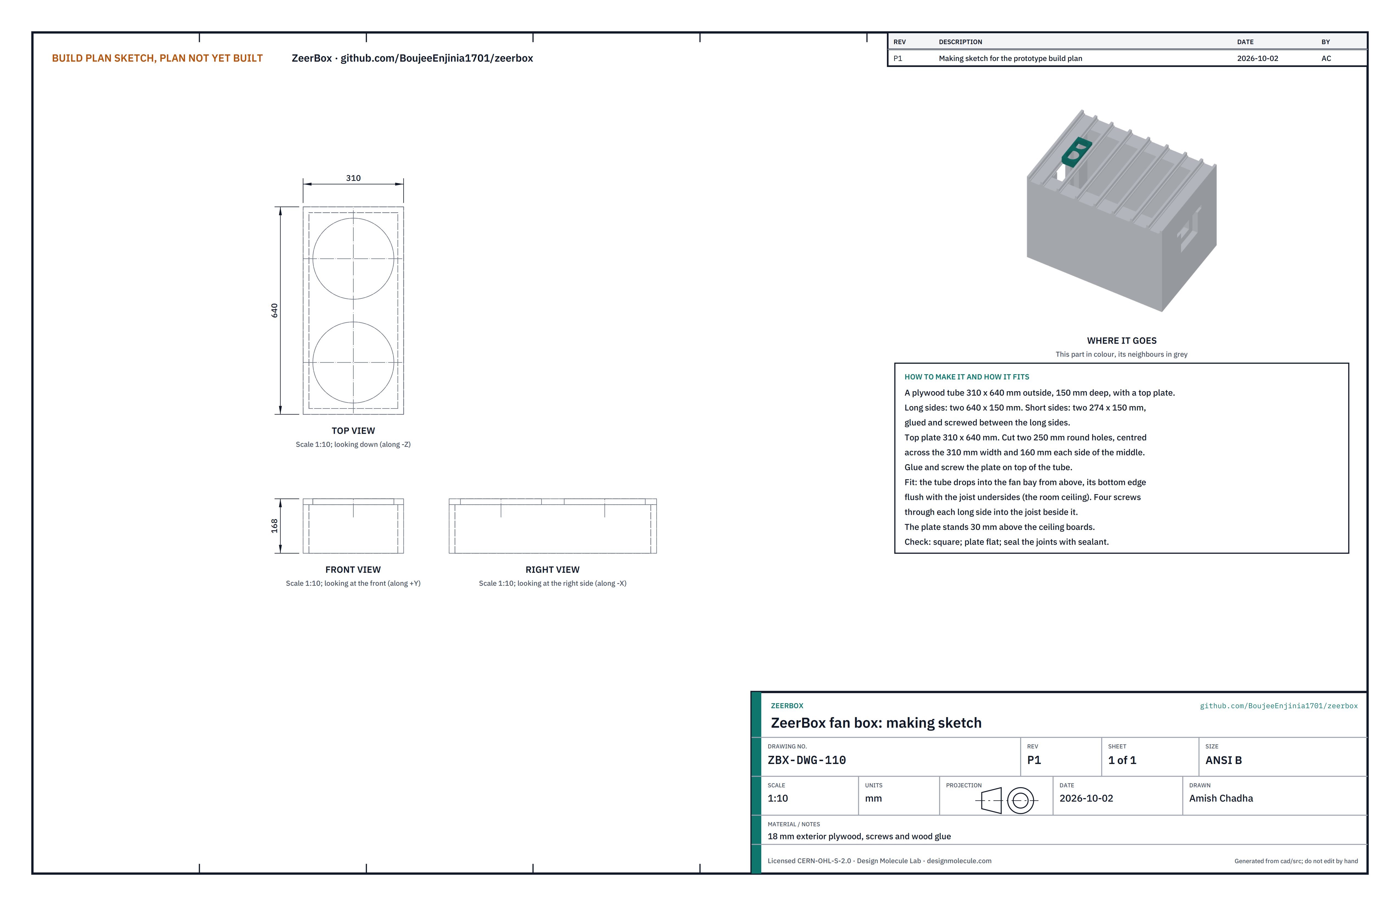
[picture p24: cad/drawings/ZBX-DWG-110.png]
Figure 16. Making sketch of the fan box


*Figure 16. Fan box making sketch (ZBX-DWG-110).*

**What it is and what it is made from.** A tube of 18 mm exterior plywood, 310 x 640 mm outside and 150 mm deep, with a top plate that carries the two fans.

**How to make it.**

1. Cut two long sides 640 x 150 mm and two short sides 274 x 150 mm. Glue and screw the short sides between the long sides.
2. Cut the top plate 310 x 640 mm. Cut two 250 mm holes, centred across its width and 160 mm each side of its middle.
3. Glue and screw the plate on top of the tube. Seal the joints.

**How it fits the parts next to it.**

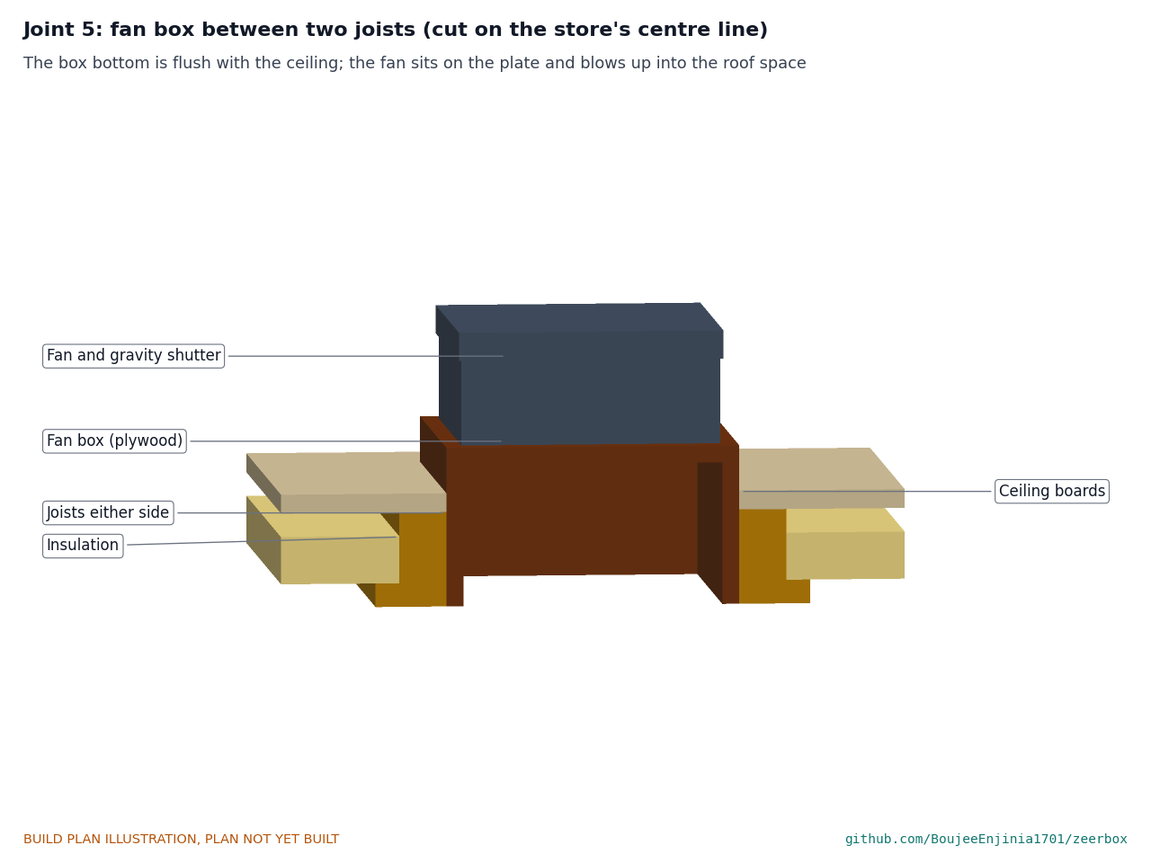
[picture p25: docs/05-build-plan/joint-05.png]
Figure 17. Joint 5: fan box between two joists


*Figure 17. The box bottom is flush with the ceiling; the fans sit on the plate and blow up into the roof space.*

The tube drops into the fan bay from above, its bottom edge flush with the joist undersides, and is held by four screws through each long side into the joist beside it. The plate stands 30 mm above the ceiling boards. The fan shutters stay at least 100 mm below the roof framing.

**Check before moving on.** Square; plate flat; the fan frames fit over the holes.

### 3.11 Roof beams (make 2)

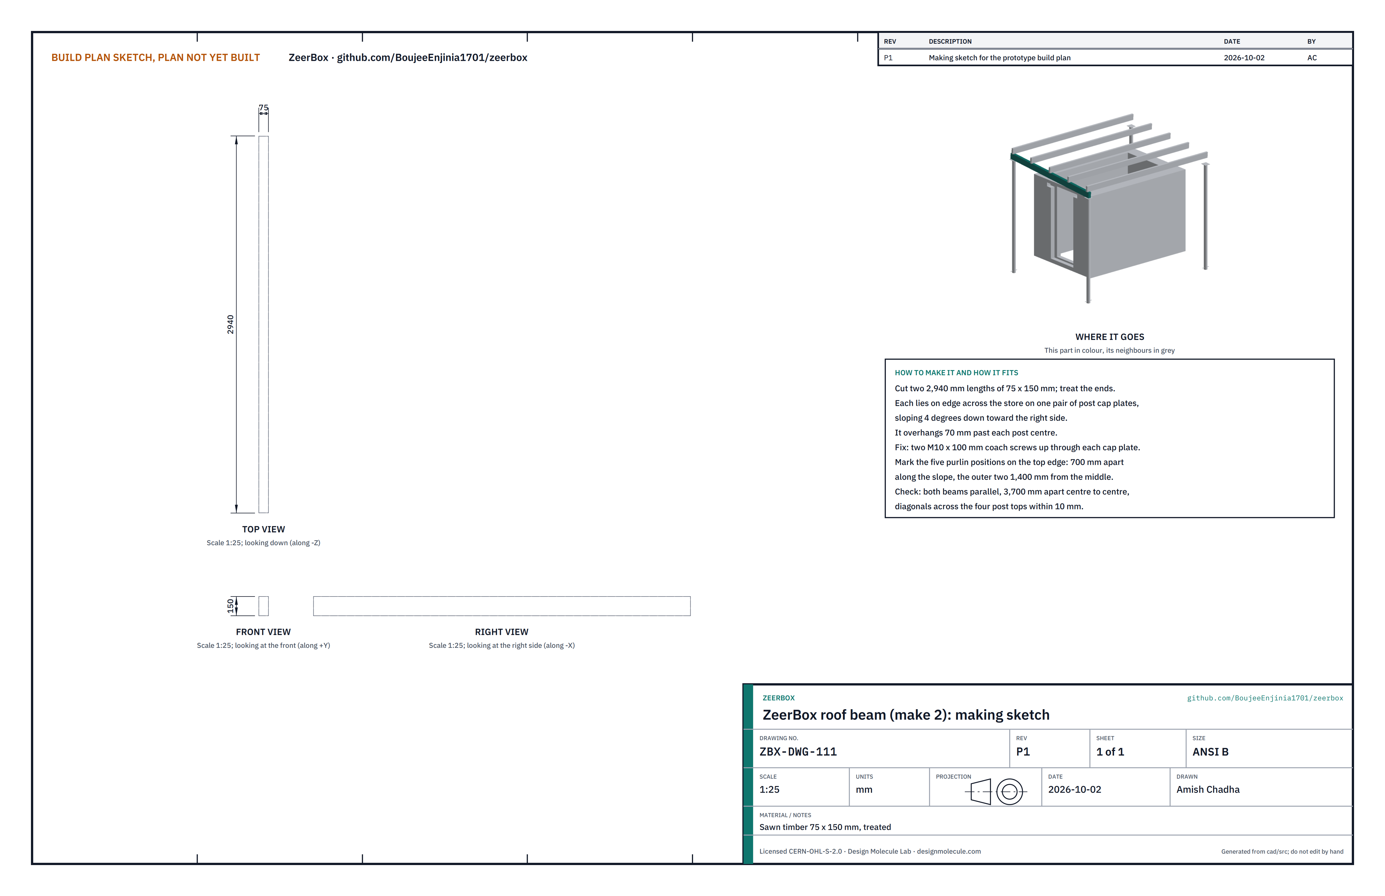
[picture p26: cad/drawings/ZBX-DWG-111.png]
Figure 18. Making sketch of the roof beam


*Figure 18. Roof beam making sketch (ZBX-DWG-111).*

**What it is and what it is made from.** Sawn, treated timber 75 x 150 mm, 2,940 mm long.

**How to make it.**

1. Cut two lengths and treat the ends.
2. Mark the five purlin positions on the top edge: 700 mm apart along the beam, the outer two 1,400 mm from its middle.

**How it fits the parts next to it.**

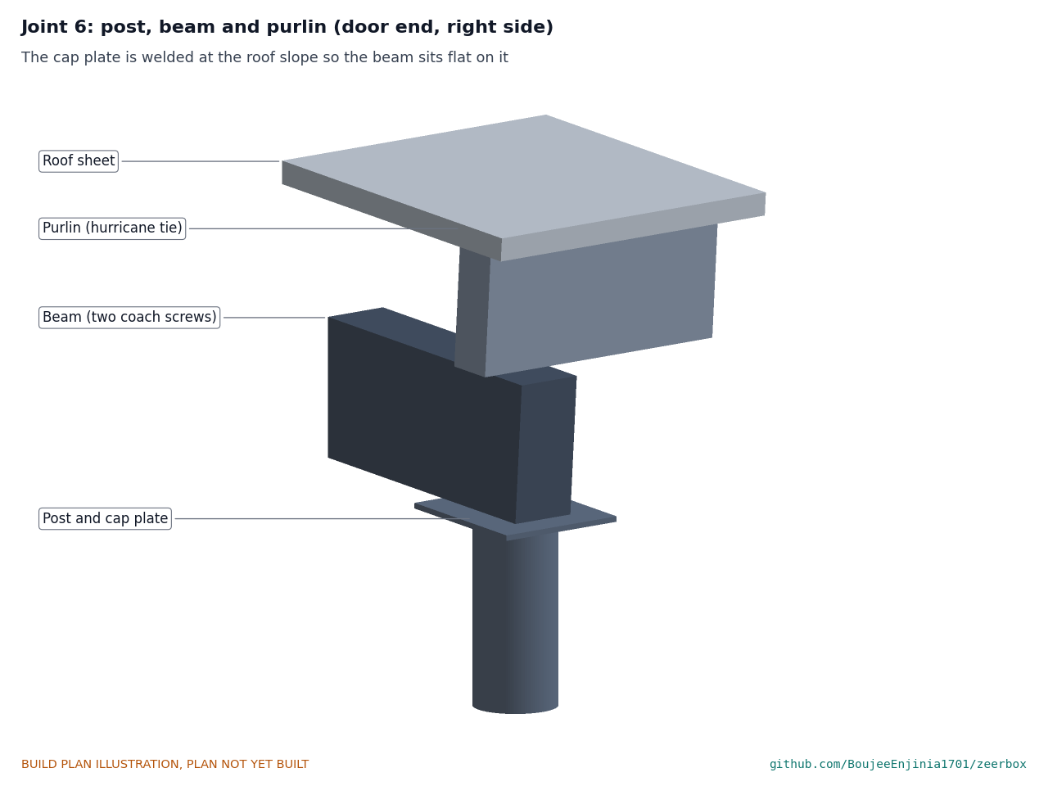
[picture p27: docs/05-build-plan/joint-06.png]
Figure 19. Joint 6: post, beam and purlin


*Figure 19. The cap plate is welded at the roof slope, so the beam sits flat on it.*

Each beam lies on edge across the store on one pair of cap plates, sloping 4° down to the right and overhanging 70 mm past each post centre. Two M10 x 100 mm coach screws go up through each cap plate into the beam.

**Check before moving on.** Beams parallel and 3,700 mm apart centre to centre; diagonals across the four post tops within 10 mm.

### 3.12 Purlins (make 5)

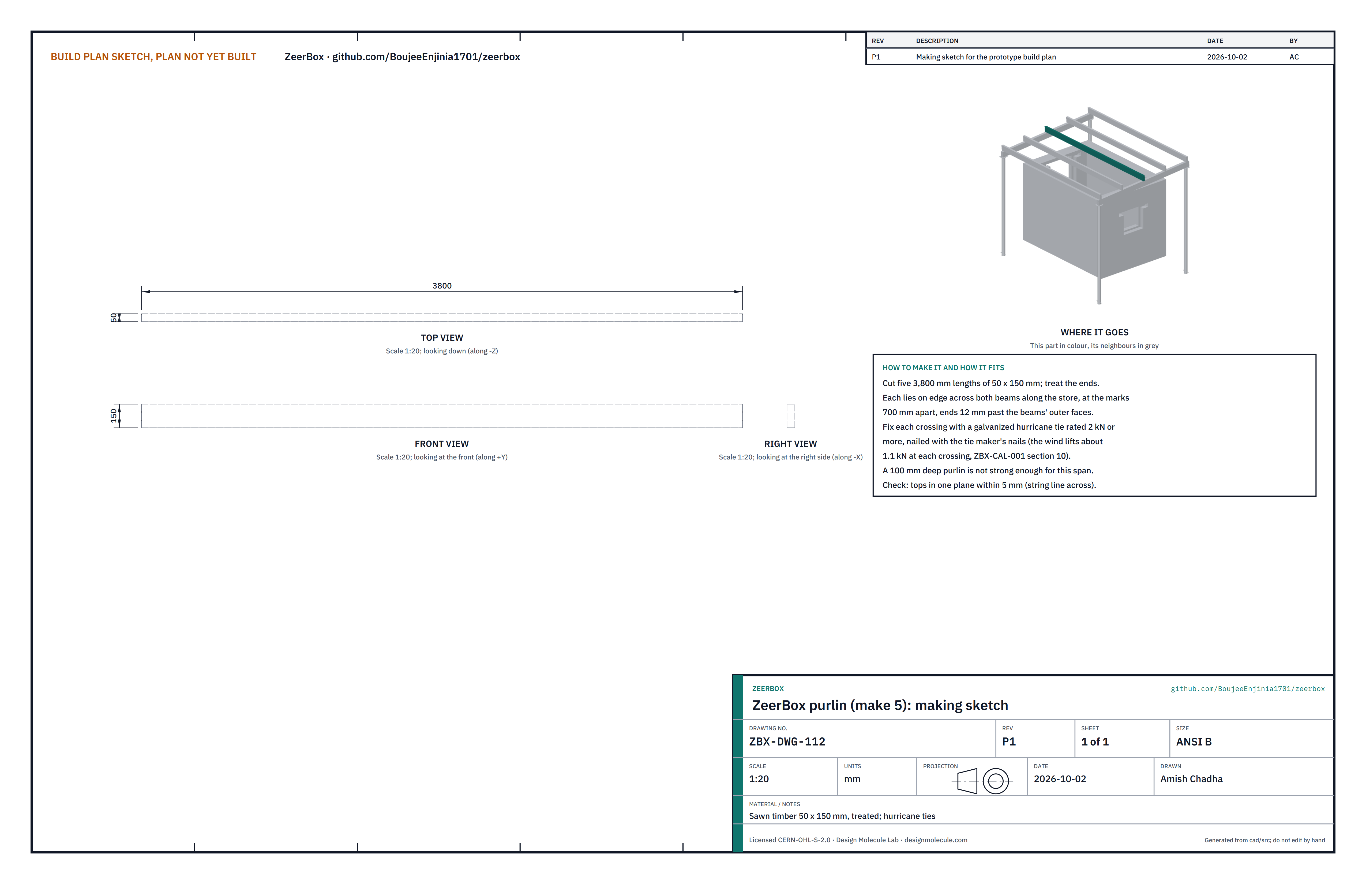
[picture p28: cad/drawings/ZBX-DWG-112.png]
Figure 20. Making sketch of the purlin


*Figure 20. Purlin making sketch (ZBX-DWG-112).*

**What it is and what it is made from.** Sawn, treated timber 50 x 150 mm, 3,800 mm long, and ten galvanized hurricane ties rated 2 kN or more.

**How to make it.** Cut five lengths and treat the ends. A 100 mm deep purlin is not strong enough for this span.

**How it fits the parts next to it.** Each purlin lies on edge across both beams, along the store, at the marks 700 mm apart, its ends 12 mm past the beams' outer faces. A hurricane tie at every crossing, nailed with the tie maker's nails, holds it down; the wind lifts about 1.1 kN at each crossing (Figure 19). The roof sheets are screwed to the purlins.

**Check before moving on.** Purlin tops in one plane within 5 mm, checked with a string line.

### 3.13 Panel mounting frames (make 2, a left and a right)

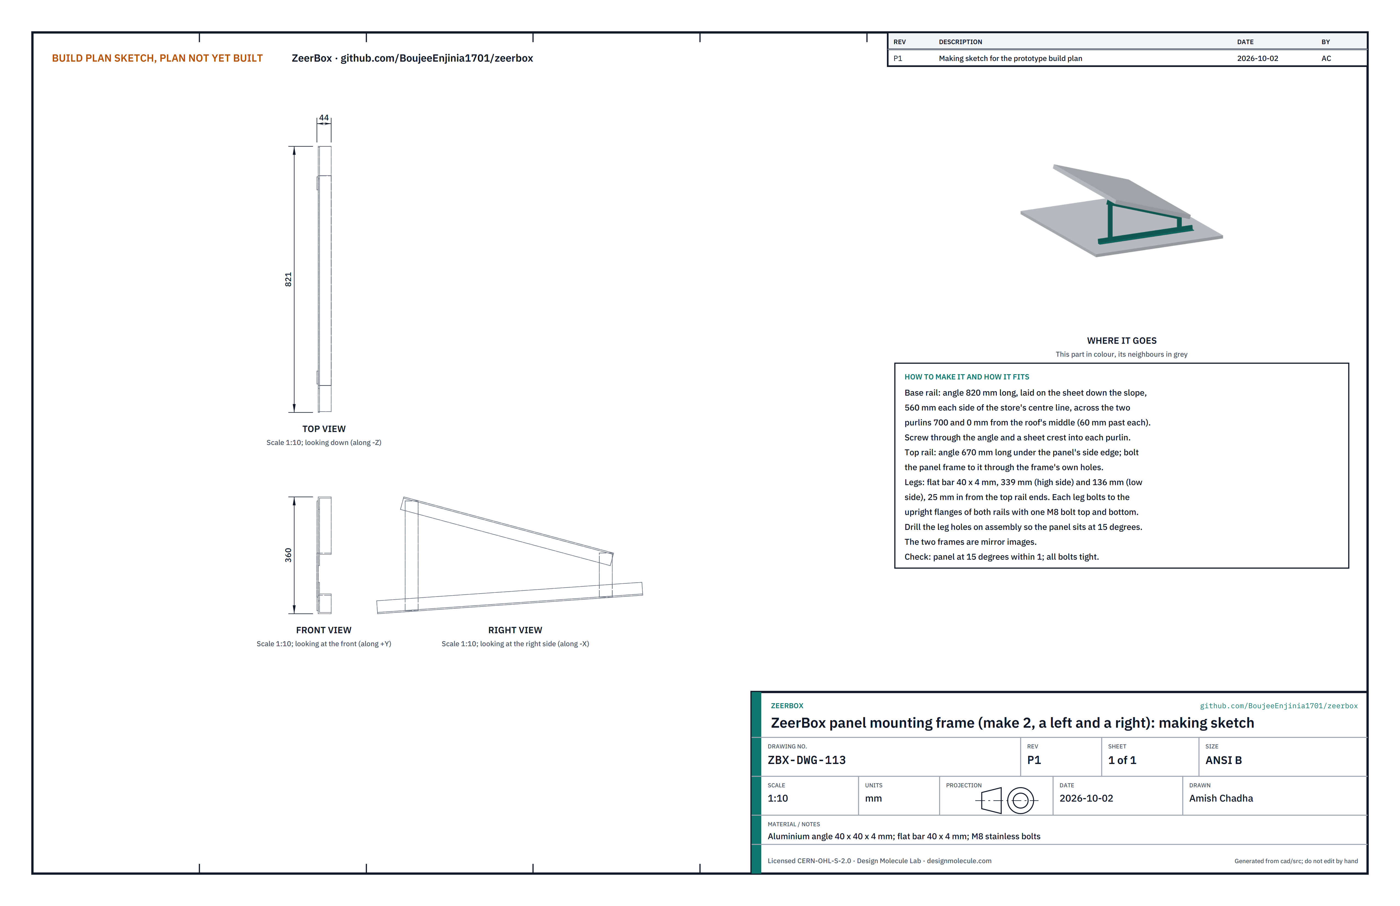
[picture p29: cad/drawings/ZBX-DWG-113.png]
Figure 21. Making sketch of the panel mounting frame


*Figure 21. Panel mounting frame making sketch (ZBX-DWG-113).*

**What it is and what it is made from.** Per frame: an aluminium angle 40 x 40 x 4 mm base rail 820 mm long, a top rail of the same angle 670 mm long, and two legs of 40 x 4 mm aluminium flat bar, 339 mm and 136 mm long; M8 stainless bolts.

**How to make it.**

1. Cut the rails and legs; deburr.
2. Drill the base rail for two roofing screws at each purlin crossing, 700 mm apart.
3. Drill the top rail to match the panel frame's mounting holes.
4. Drill one 9 mm hole at each end of each leg; drill the matching rail holes on assembly so the panel sits at 15°.
5. The two frames are mirror images.

**How it fits the parts next to it.**

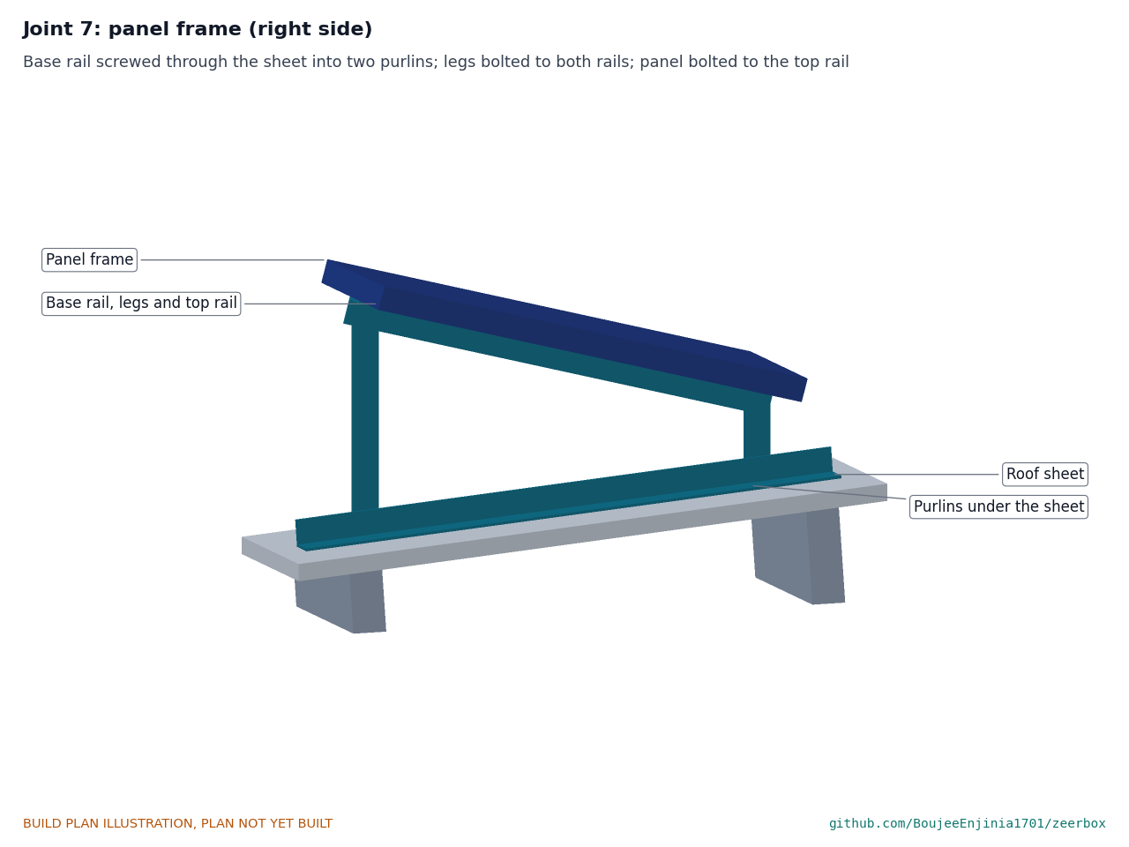
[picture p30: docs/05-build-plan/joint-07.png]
Figure 22. Joint 7: panel frame


*Figure 22. Base rail screwed through the sheet into two purlins; legs bolted to both rails; panel bolted to the top rail.*

The base rails lie on the sheet down the slope, 560 mm each side of the store's centre line, across the purlins at 700 mm and 0 mm from the roof's middle, 60 mm past each. Each leg stands 25 mm in from a top rail end and bolts to the upright flanges of both rails.

**Check before moving on.** Panel at 15° within 1°; all bolts tight.

### 3.14 Pad opening lining

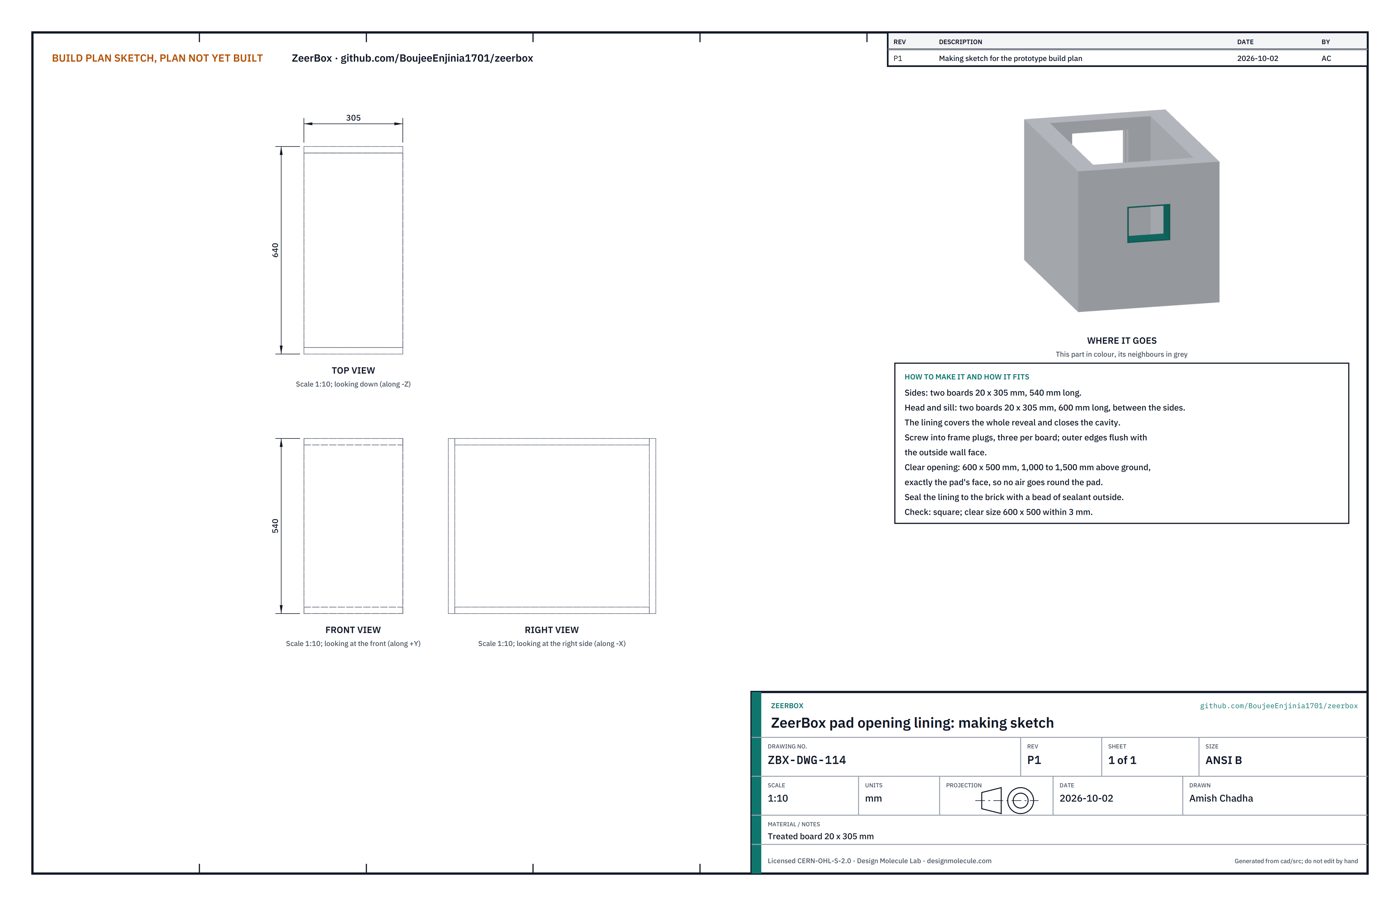
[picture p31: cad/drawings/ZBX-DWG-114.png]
Figure 23. Making sketch of the pad opening lining


*Figure 23. Pad opening lining making sketch (ZBX-DWG-114).*

**What it is and what it is made from.** Four treated boards, 20 x 305 mm, that line the pad opening and close the cavity.

**How to make it.** Cut two sides 540 mm long and a head and a sill 600 mm long.

**How it fits the parts next to it.** The head and sill fit between the sides; the outer edges are flush with the outside wall face; three screws in frame plugs per board. The clear opening is 600 x 500 mm, from 1,000 to 1,500 mm above ground: exactly the pad's face, so no air goes round the pad. A bead of sealant seals the lining to the brick outside.

**Check before moving on.** Square; clear size 600 x 500 mm within 3 mm.

### 3.15 Pad frame

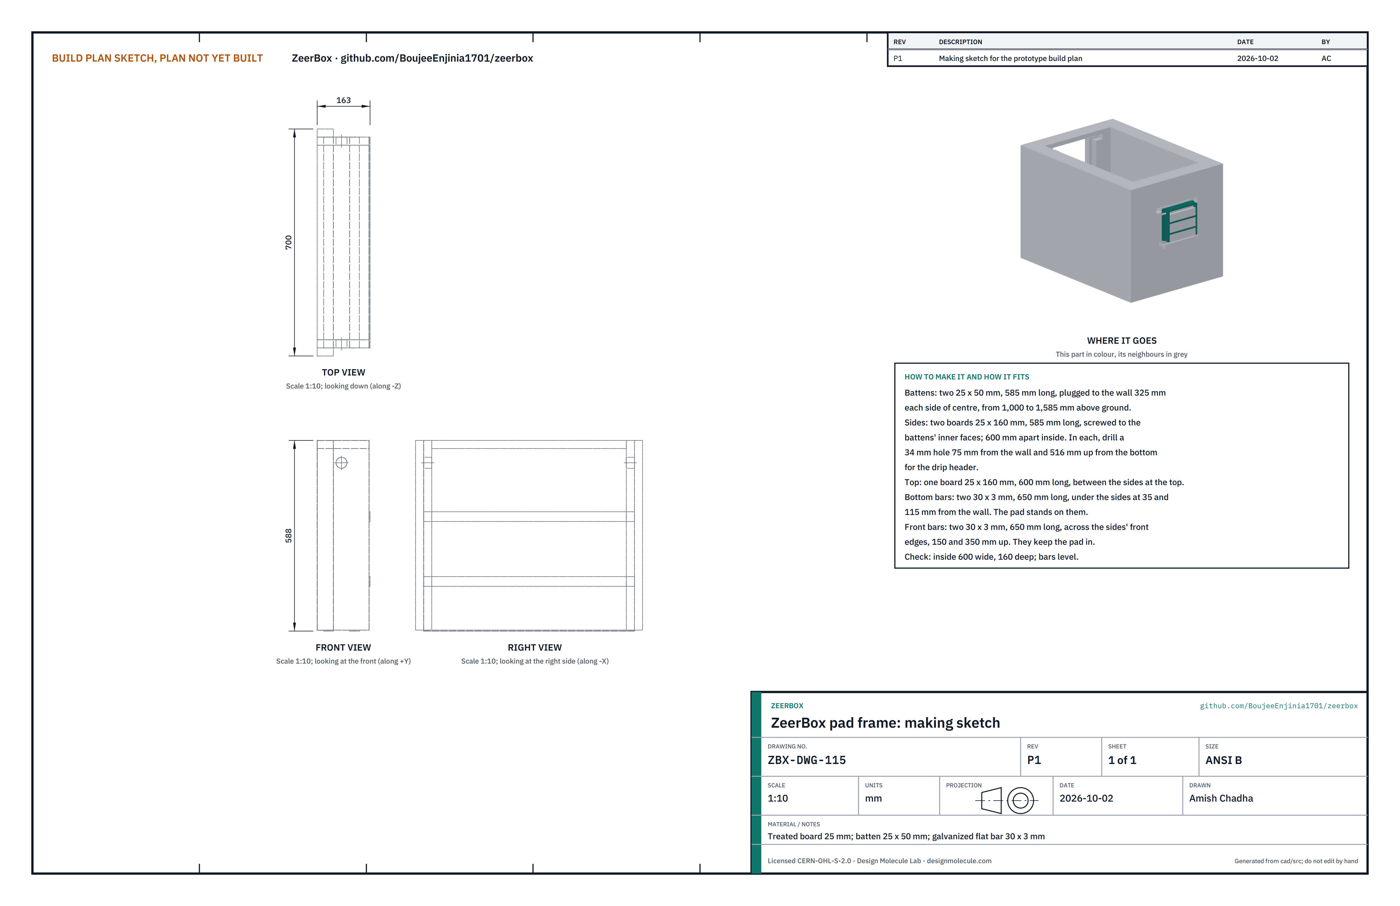
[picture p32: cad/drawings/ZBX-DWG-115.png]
Figure 24. Making sketch of the pad frame


*Figure 24. Pad frame making sketch (ZBX-DWG-115).*

**What it is and what it is made from.** Two 25 x 50 mm wall battens; two side boards and a top board of 25 mm treated board, 160 mm deep; four galvanized flat bars 30 x 3 mm, 650 mm long.

**How to make it.**

1. Cut the battens and sides 585 mm long and the top 600 mm long.
2. In each side, drill a 34 mm hole 75 mm from the back edge and 516 mm up from the bottom, for the drip header.
3. Cut the four bars and drill them for two screws at each end.

**How it fits the parts next to it.**

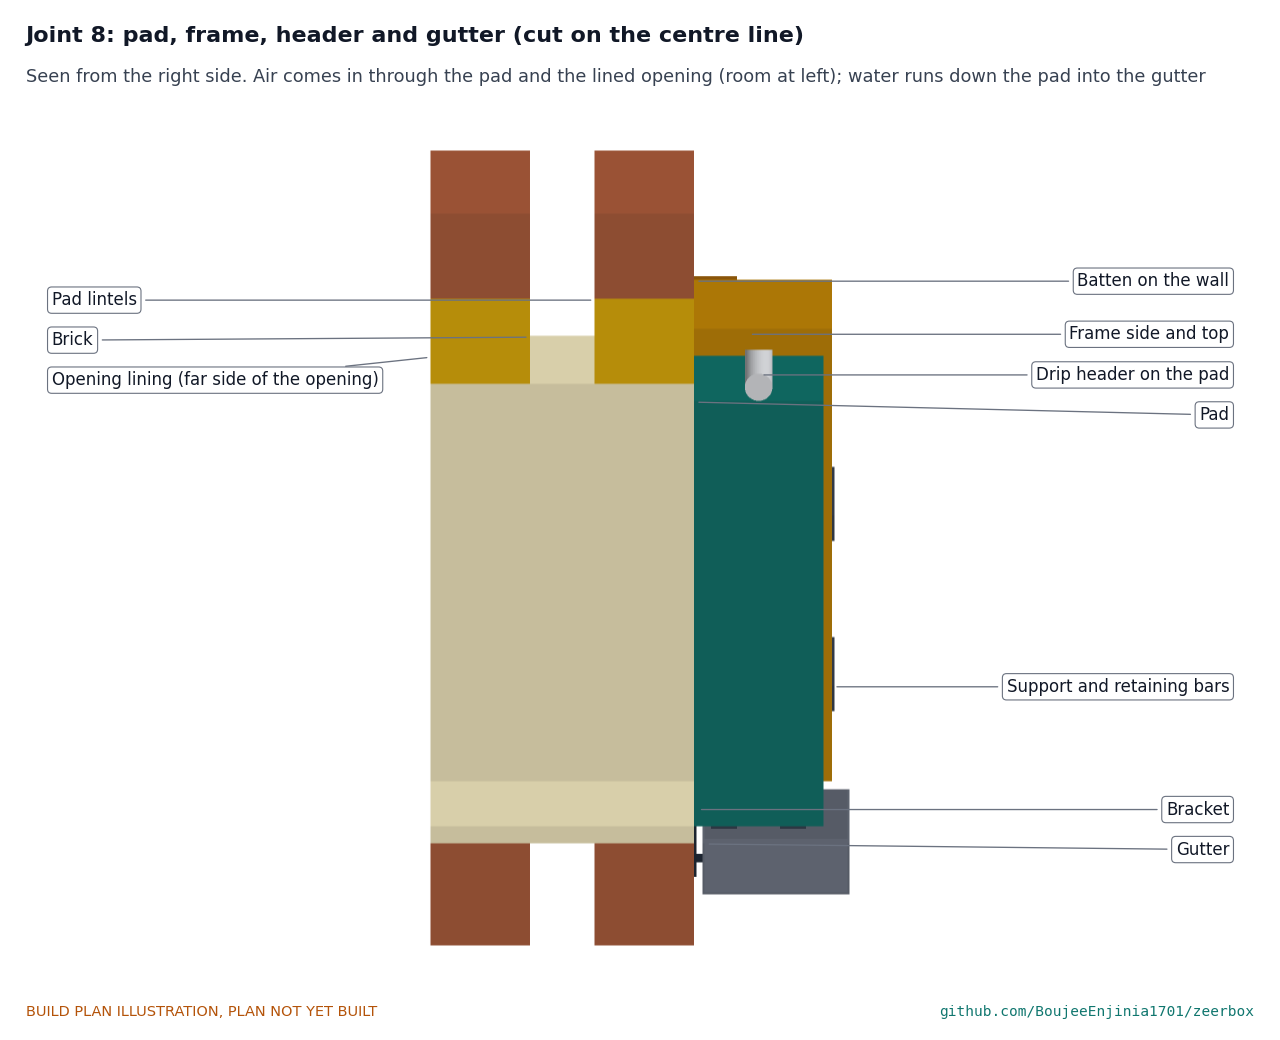
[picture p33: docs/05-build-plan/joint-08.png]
Figure 25. Joint 8: pad, frame, header and gutter


*Figure 25. Section on the centre line, seen from the right: the lined opening, the pad on its bars inside the frame, the header on the pad, the gutter below.*

The battens are plugged to the wall 325 mm each side of centre, from 1,000 to 1,585 mm above ground. The sides are screwed to the battens' inner faces, 600 mm apart inside, and the top fits between them. The two bottom bars run under the sides, 35 and 115 mm from the wall; the pad stands on them. The two front bars cross the sides' front edges 150 and 350 mm up and keep the pad in.

**Check before moving on.** Inside 600 mm wide and 160 mm deep; bottom bars level.

### 3.16 Drip header

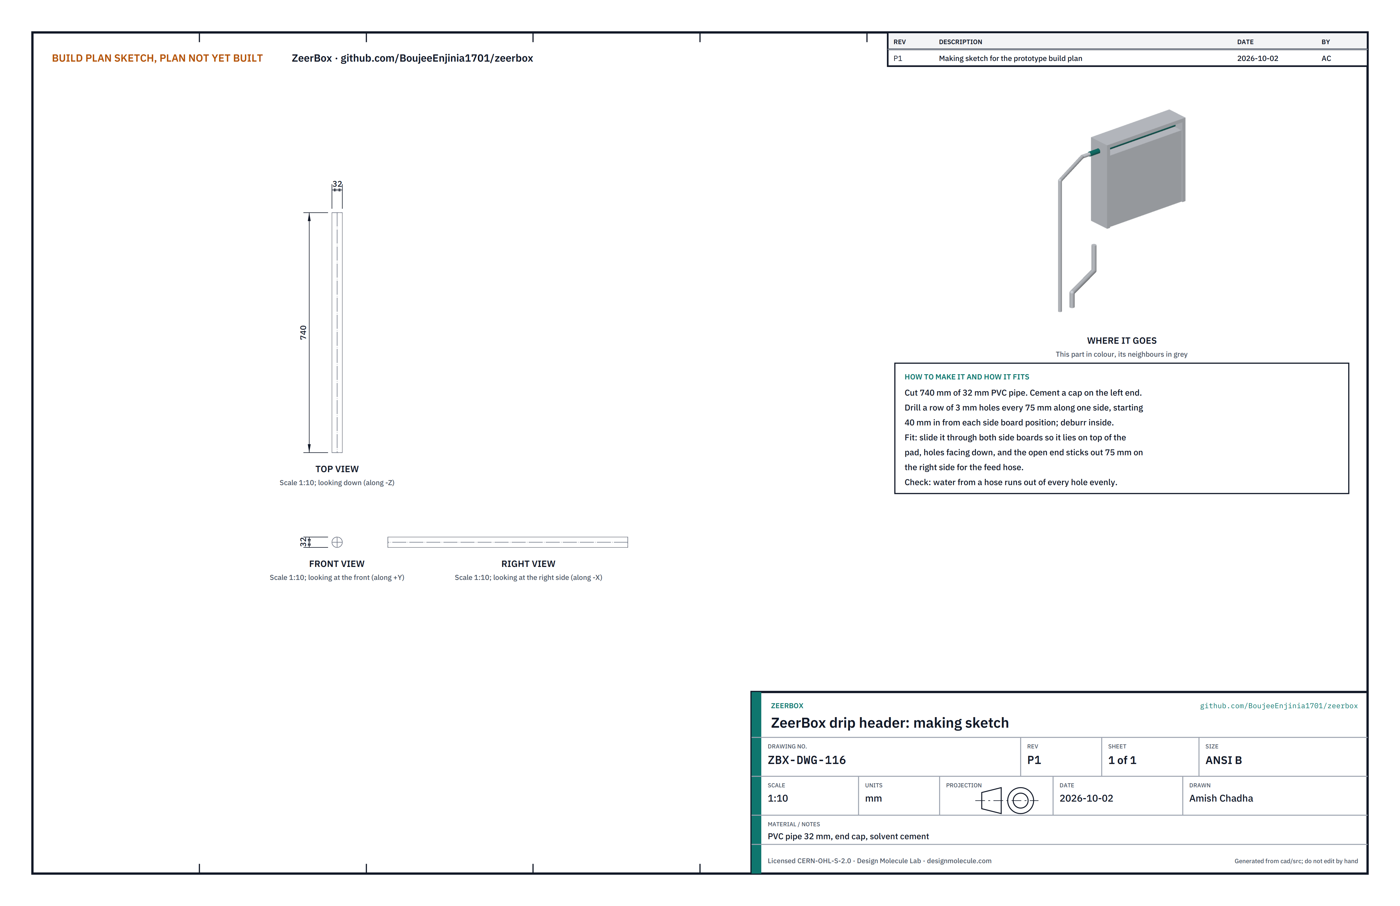
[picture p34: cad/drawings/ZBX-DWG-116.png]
Figure 26. Making sketch of the drip header


*Figure 26. Drip header making sketch (ZBX-DWG-116).*

**What it is and what it is made from.** 740 mm of 32 mm PVC pipe with an end cap.

**How to make it.**

1. Cut the pipe and cement a cap on the left end.
2. Drill a row of 3 mm holes every 75 mm along one side, between the frame sides; deburr inside.

**How it fits the parts next to it.** It slides through both side boards and lies on top of the pad, holes facing down, with its open end 75 mm out on the right for the feed hose (Figure 25).

**Check before moving on.** Water from a hose runs out of every hole evenly.

### 3.17 Return gutter and brackets

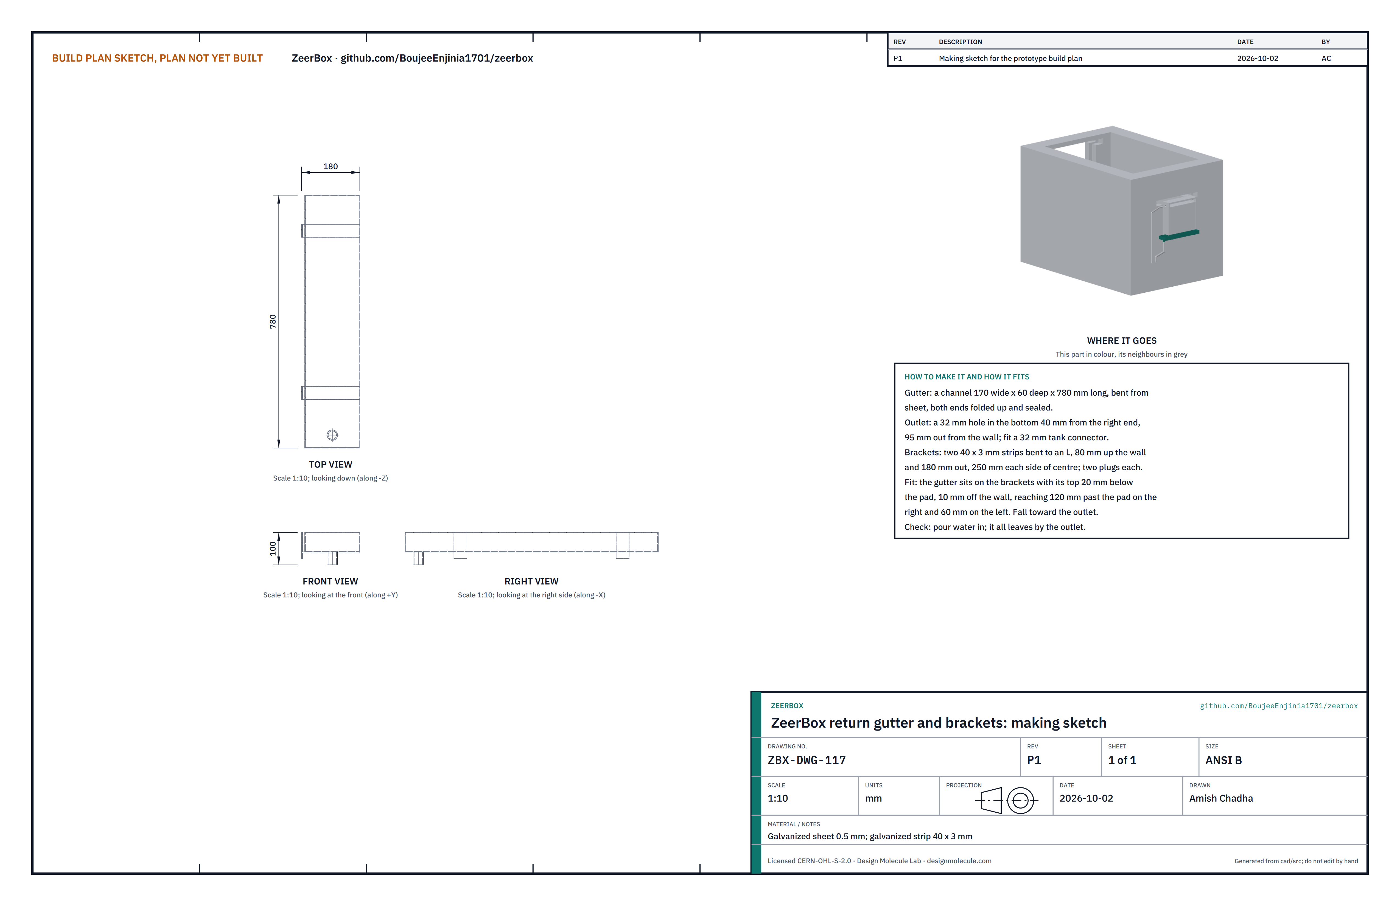
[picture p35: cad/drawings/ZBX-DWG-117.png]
Figure 27. Making sketch of the gutter


*Figure 27. Return gutter and brackets making sketch (ZBX-DWG-117).*

**What it is and what it is made from.** A channel bent from 0.5 mm galvanized sheet, 170 mm wide, 60 mm deep and 780 mm long, with a 32 mm tank connector outlet; two brackets of 40 x 3 mm galvanized strip.

**How to make it.**

1. Bend the channel; fold both ends up and seal them.
2. Cut a 32 mm hole in the bottom 40 mm from the right end and 95 mm out from the wall; fit the tank connector.
3. Bend each bracket to an L, 80 mm up the wall and 180 mm out; drill for two plugs.

**How it fits the parts next to it.** The brackets are plugged to the wall 250 mm each side of centre. The gutter sits on them 10 mm off the wall with its top 20 mm below the pad, reaching 120 mm past the pad on the right and 60 mm on the left, with a slight fall to the outlet (Figure 25).

**Check before moving on.** Pour water in: it all leaves by the outlet.

### 3.18 Shelving racks (make 2)

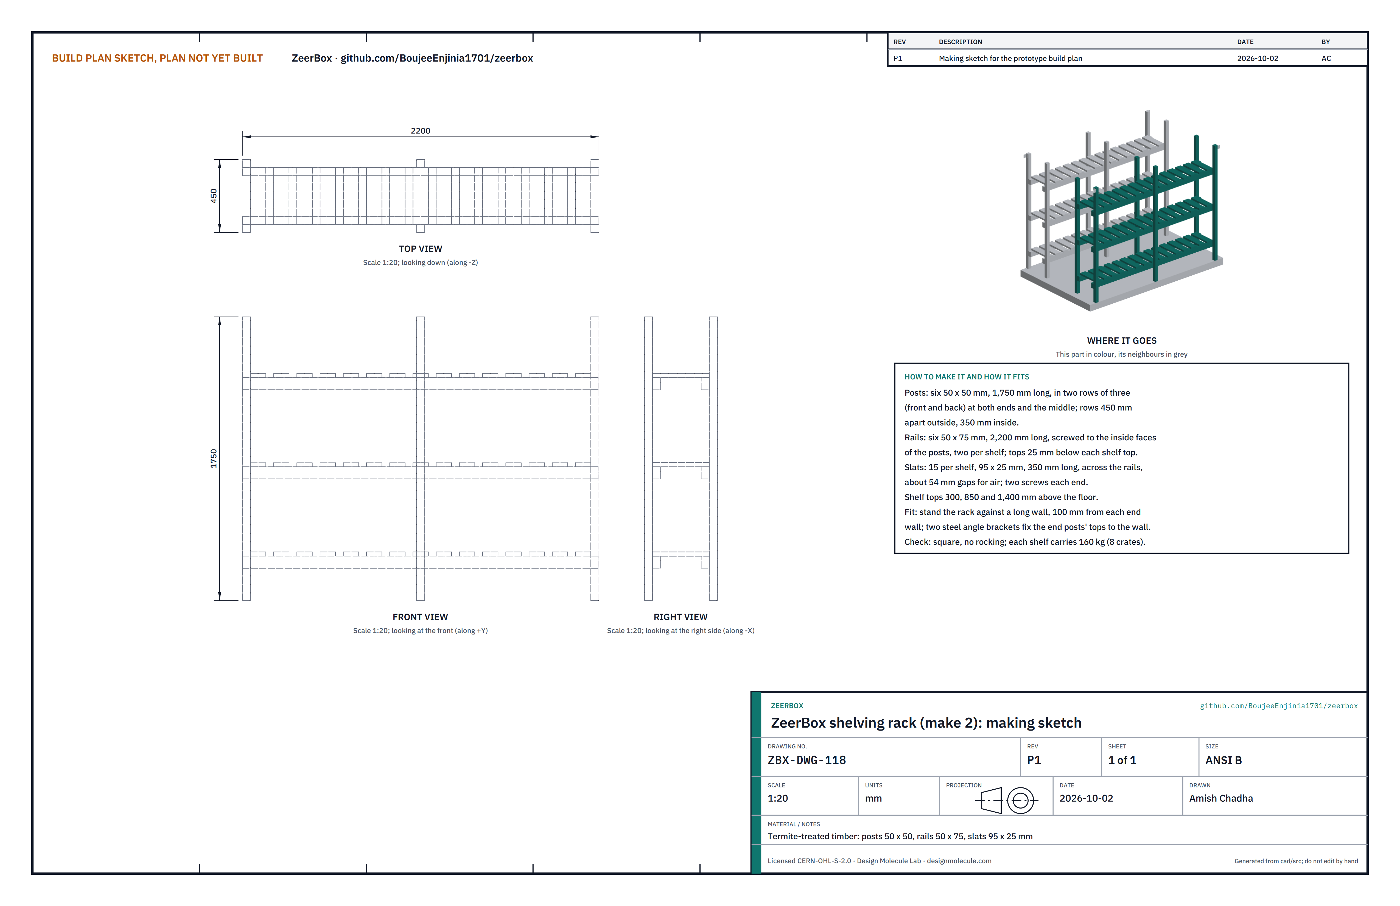
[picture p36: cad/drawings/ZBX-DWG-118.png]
Figure 28. Making sketch of the rack


*Figure 28. Shelving rack making sketch (ZBX-DWG-118).*

**What it is and what it is made from.** Termite-treated timber: six 50 x 50 mm posts, six 50 x 75 mm rails, 45 slats 95 x 25 mm; two 40 x 40 x 3 mm steel angle brackets.

**How to make it.**

1. Cut the posts 1,750 mm, the rails 2,200 mm and the slats 350 mm long.
2. Stand the posts in two rows of three, at both ends and the middle; the rows are 450 mm apart outside and 350 mm inside.
3. Screw two rails to the inside faces of the posts at each shelf, their tops 25 mm below the shelf top.
4. Screw 15 slats across the rails at each shelf, two screws each end, with about 54 mm gaps for air. Shelf tops are 300, 850 and 1,400 mm above the floor.

**How it fits the parts next to it.**

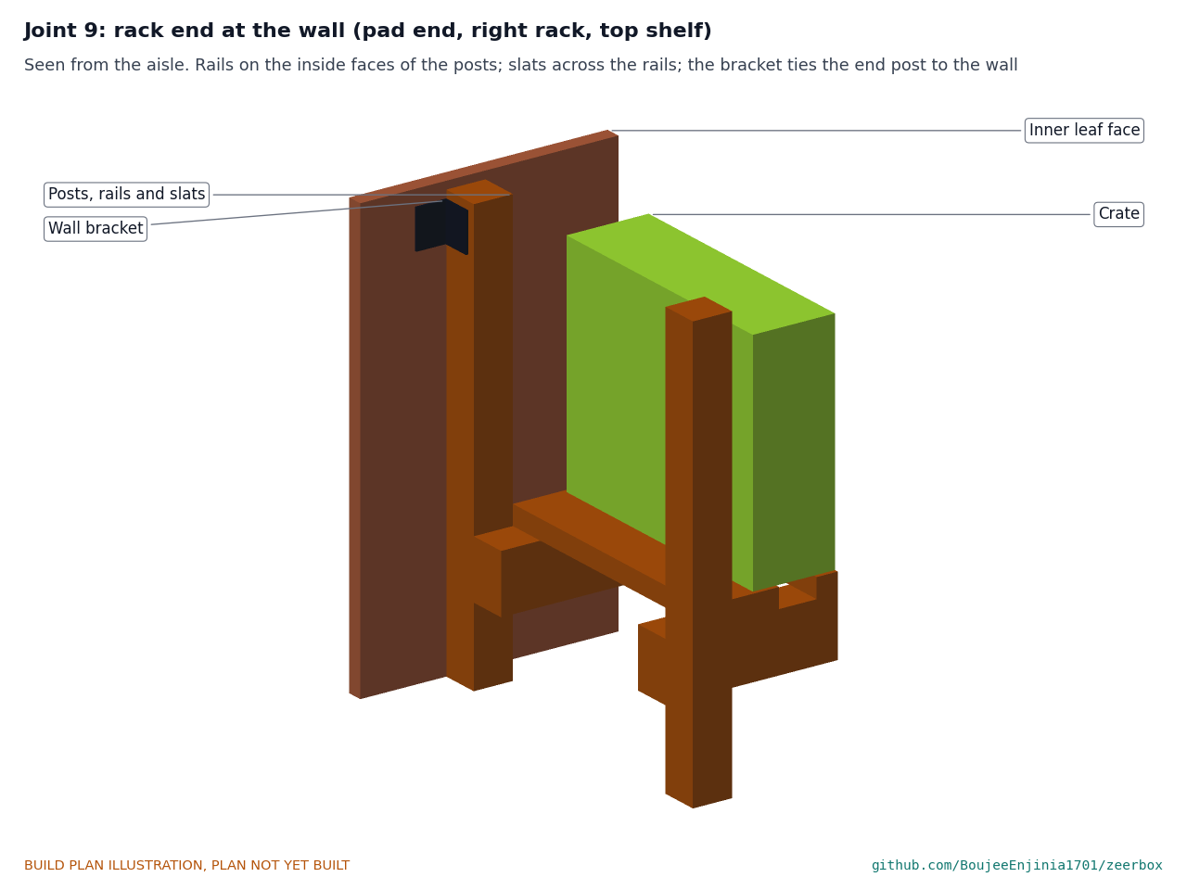
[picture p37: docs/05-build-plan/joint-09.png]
Figure 29. Joint 9: rack end at the wall


*Figure 29. Seen from the aisle: rails on the inside faces of the posts, slats across the rails, a bracket tying the end post to the wall.*

Each rack stands on the floor against a long wall, 100 mm from each end wall, leaving a 600 mm aisle. A steel angle bracket ties the top of each end post to the wall.

**Check before moving on.** Square, no rocking; each shelf carries 160 kg, eight full crates.

### 3.19 Bought components

Buy to specification, not brand. Line numbers are those of the bill of materials.

- **Cellulose pad (line 6).** 150 mm cross-fluted evaporative cooling pad, 600 x 500 mm, flutes at the standard 45° and 15° angles.
- **Exhaust fans (line 8).** Two 250 mm 12 V DC axial fans, about 12 W and about 400 m³/h free air, with a square frame no wider than 290 mm, finger guards on both faces and gravity shutters.
- **Sump drum, pump and hoses (line 7).** A 60 L plastic drum with a tight lid; a 12 V submersible pump of about 6 W giving 3.6 L/min at 2 m head; a float switch; 25 mm feed hose and 32 mm return hose with clips. Drill the lid for the two hoses and a cable gland.
- **Solar panel (line 10).** 150 W monocrystalline, about 1,480 x 670 x 35 mm, Vmp about 18 V, Isc about 9 A, with mounting holes in the back flange of its frame.
- **Power box (line 11).** A 20 A PWM charge controller for 12.8 V lithium iron phosphate, a 12.8 V 12 Ah LiFePO4 battery with a BMS rated for 10 A charge or more, a 15 A fuse at the battery terminal, and a ventilated, shaded steel box with a plain door (no window), about 100 x 220 x 300 mm.
- **Controller and sensors (line 9).** A low-cost microcontroller board, two digital temperature and humidity sensors (one in a radiation shield on a strip arm), MOSFET drivers for the fans and pump, a memory card logger, a three-colour mode lamp with a 22 mm body and a clear-lid IP65 box about 80 x 200 x 250 mm. The outside sensor sits in a shield of six round plates, 46 mm across, stacked 10 mm apart on a stud that is fixed to a short strip arm.
- **Wiring and plumbing (line 14).** 2.5 mm² twin PV cable, 1.5 mm² twin load cable, 4-core 0.5 mm² sensor cable, conduit, IP65 connectors, glands, hose clips and fixings.
- **Fixings.** Frame plugs and screws, galvanized joist straps, ten hurricane ties, eight M10 x 100 mm coach screws, sealing-washer roofing screws, M8 stainless bolts, three 100 mm butt hinges, an inside push latch and a pull handle.

#### 3.19.1 Wiring

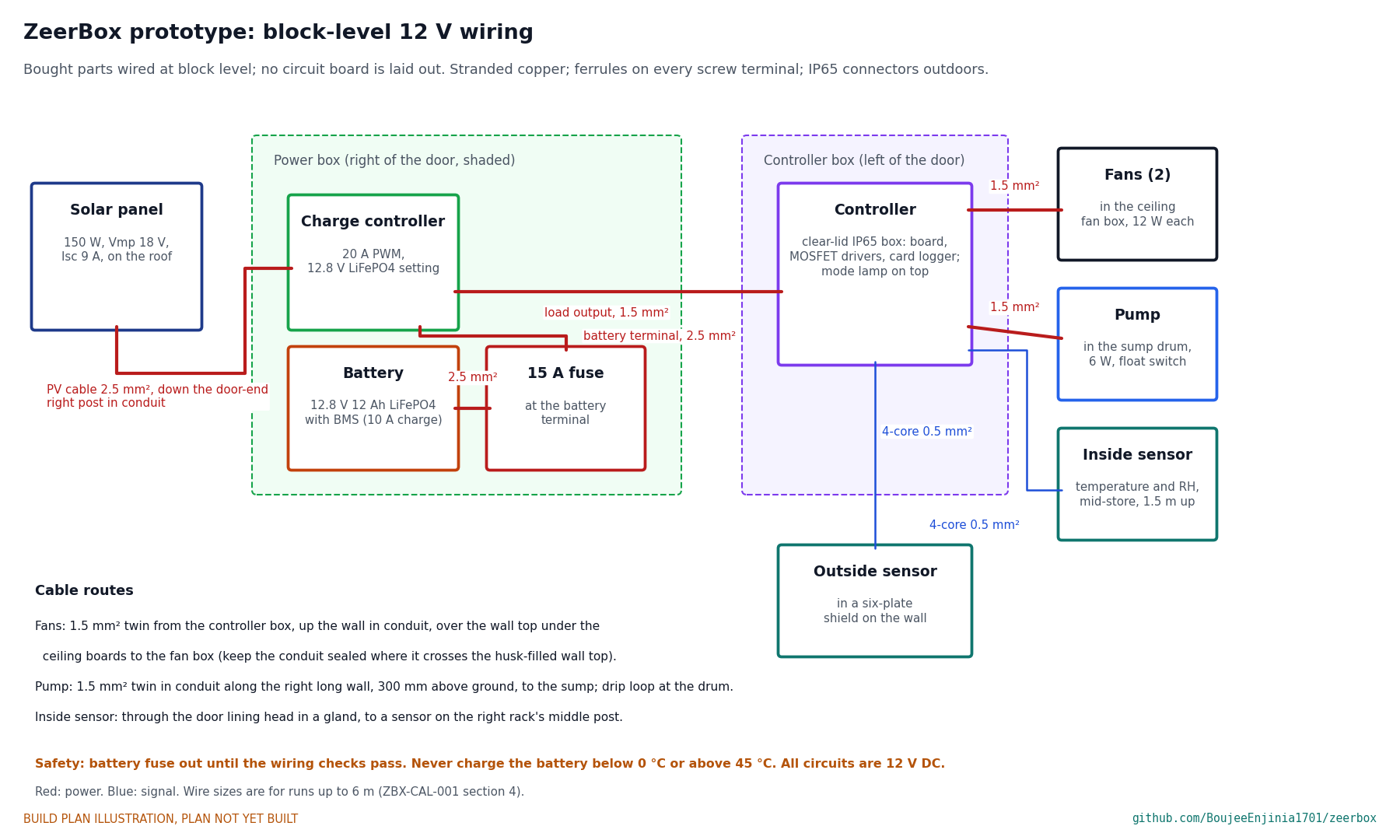
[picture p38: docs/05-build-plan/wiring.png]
Figure 30. Block-level 12 V wiring


*Figure 30. Block-level wiring with wire sizes. No circuit board is laid out at this stage; bought parts are wired together.*

1. Panel to the charge controller's panel terminals: 2.5 mm² PV cable down the right front post in conduit.
2. Charge controller to the battery through the 15 A fuse at the battery terminal: 2.5 mm².
3. Charge controller load output to the controller box: 1.5 mm².
4. Controller to each fan: 1.5 mm² twin, up the wall in conduit and over the wall top under the ceiling boards to the fan box. Seal the conduit where it crosses the husk-filled wall top.
5. Controller to the pump: 1.5 mm² twin in conduit along the right long wall, 300 mm above ground, with a drip loop at the drum.
6. Inside sensor: 4-core 0.5 mm² through a gland in the door lining head, to a sensor on the right rack's middle post about 1.5 m up. Outside sensor: 4-core 0.5 mm² to its shield beside the controller.

**Check before moving on.** With the fuse out, every circuit continues end to end and none reads short to another; every cable is labelled.

## 4. Putting it together

In each picture the parts already fitted are grey and the part being fitted is in colour, with an arrow showing the way it goes in.

### Step 1: cast the wall strip footing

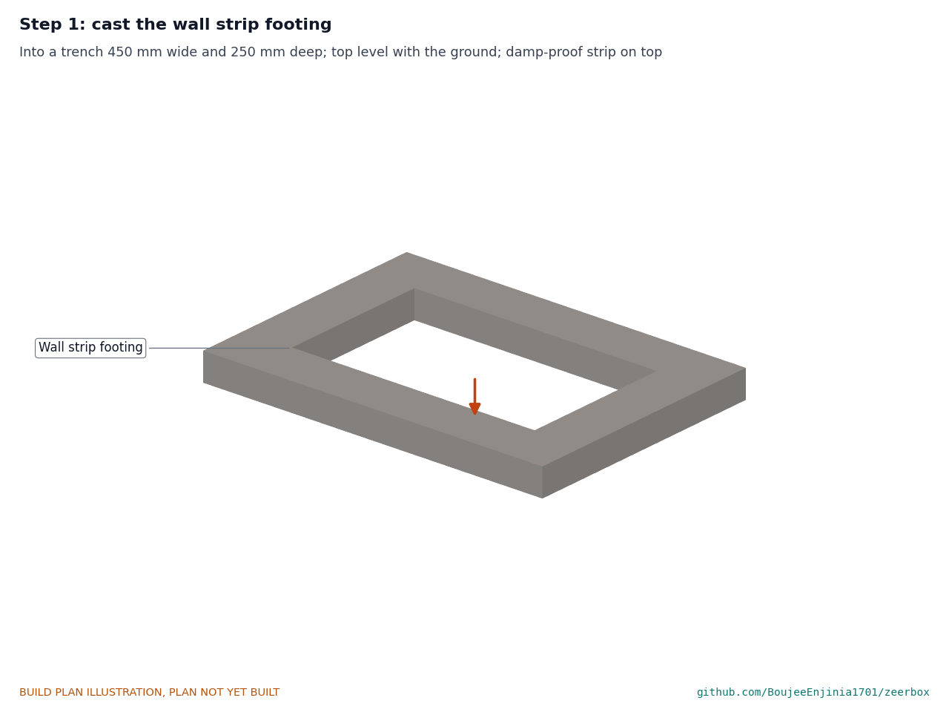
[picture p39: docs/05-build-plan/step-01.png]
Step 1


Dig and pour as section 3.1. **Hold point:** 7 days of curing before any brick is laid.

### Step 2: set the roof posts in their footings

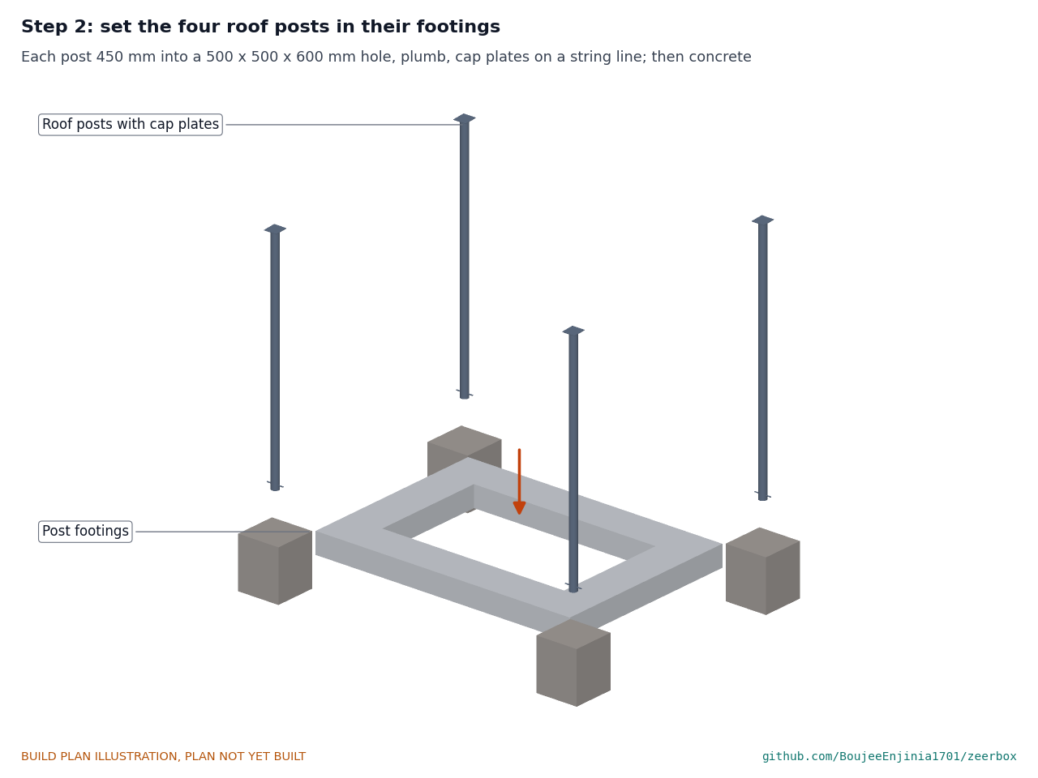
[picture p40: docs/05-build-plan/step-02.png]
Step 2


Stand each post 450 mm into its hole, plumb and braced, cap plates on the string line, then fill with concrete. Leave the bracing on for 7 days.

### Step 3: lay the walls and fill the cavity as they rise

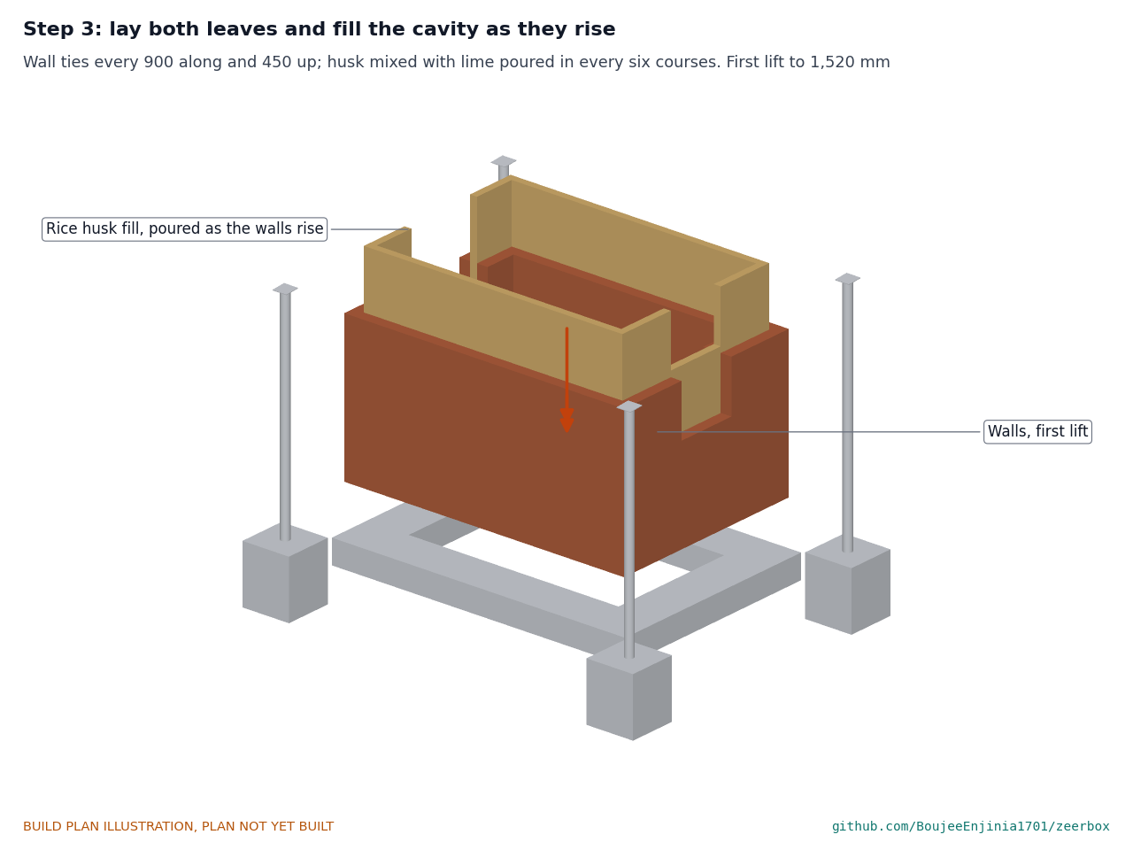
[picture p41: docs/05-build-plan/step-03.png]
Step 3


Both leaves together with wall ties; husk and lime poured in every six courses. Stop at 1,520 mm.

### Step 4: lintels over the pad opening

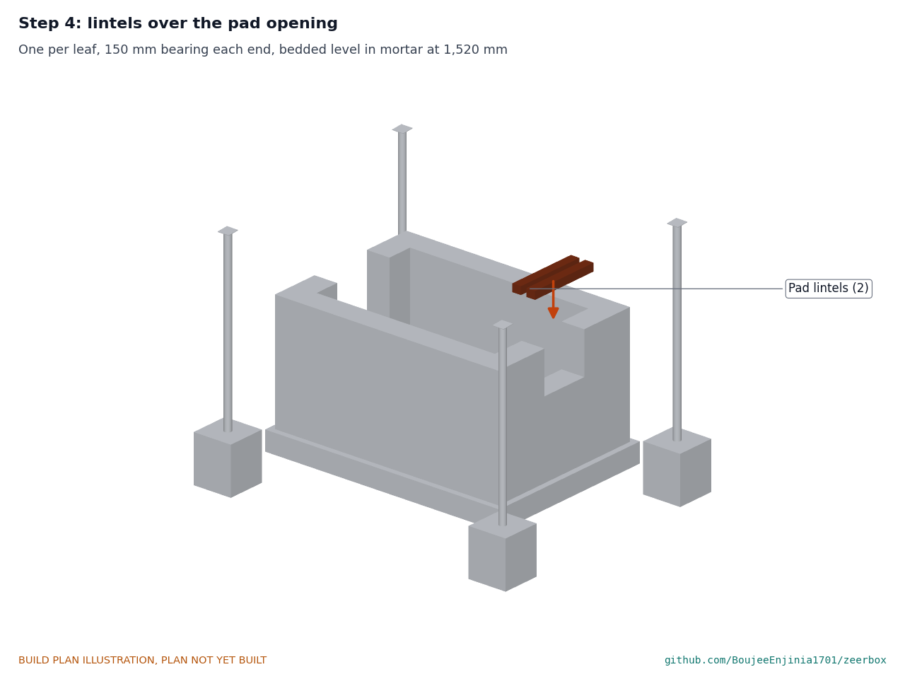
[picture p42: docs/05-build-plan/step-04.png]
Step 4


One per leaf, 150 mm bearing each end, bedded level in mortar.

### Step 5: finish the walls, door lintels and capping course

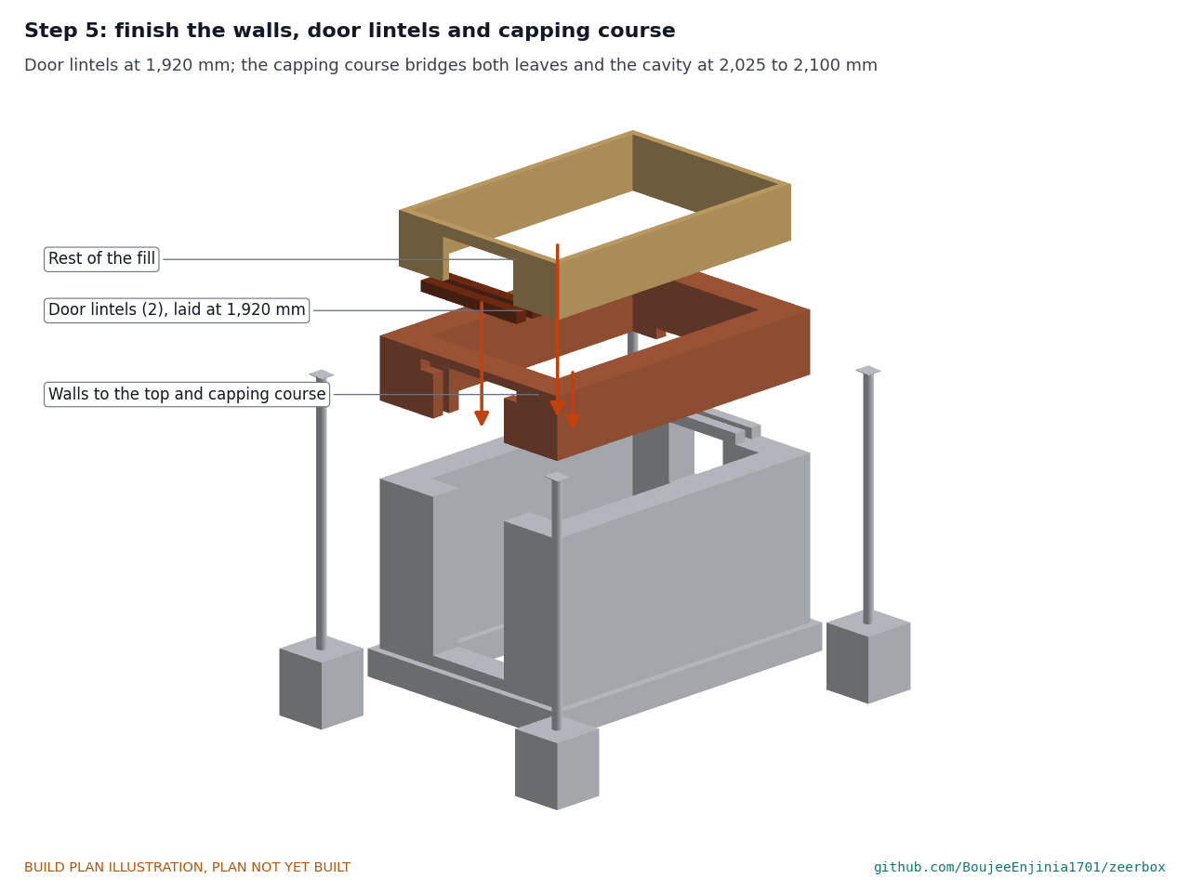
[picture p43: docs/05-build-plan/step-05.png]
Step 5


Build on to 1,920 mm, bed the door lintels, finish the walls and the fill, and lay the capping course from 2,025 to 2,100 mm. Fix the joist straps into the top course at the joist positions.

### Step 6: lay the brick floor

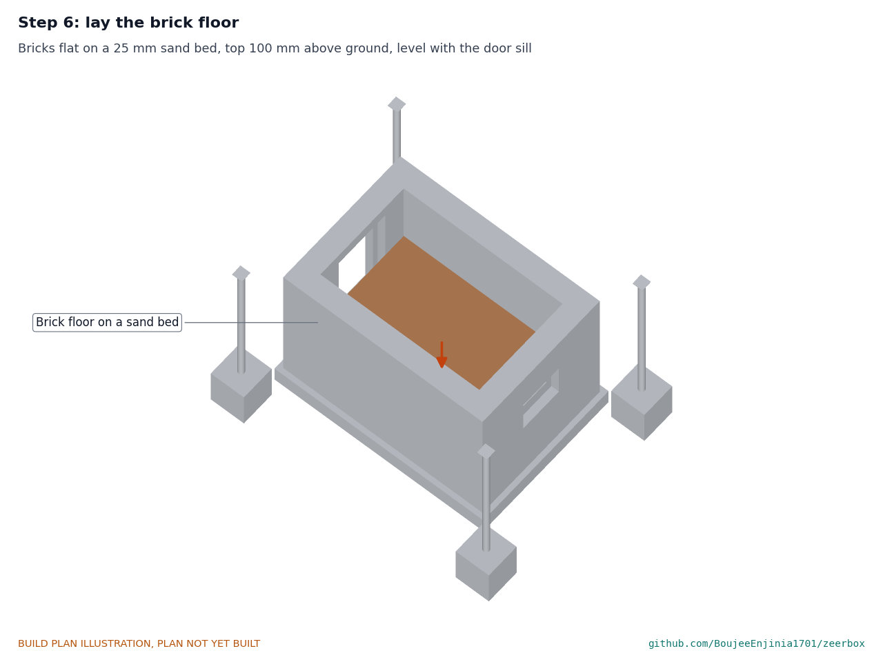
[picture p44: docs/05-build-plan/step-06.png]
Step 6


Sand bed and bricks as section 3.5.

### Step 7: line the door opening and fit the stop beads

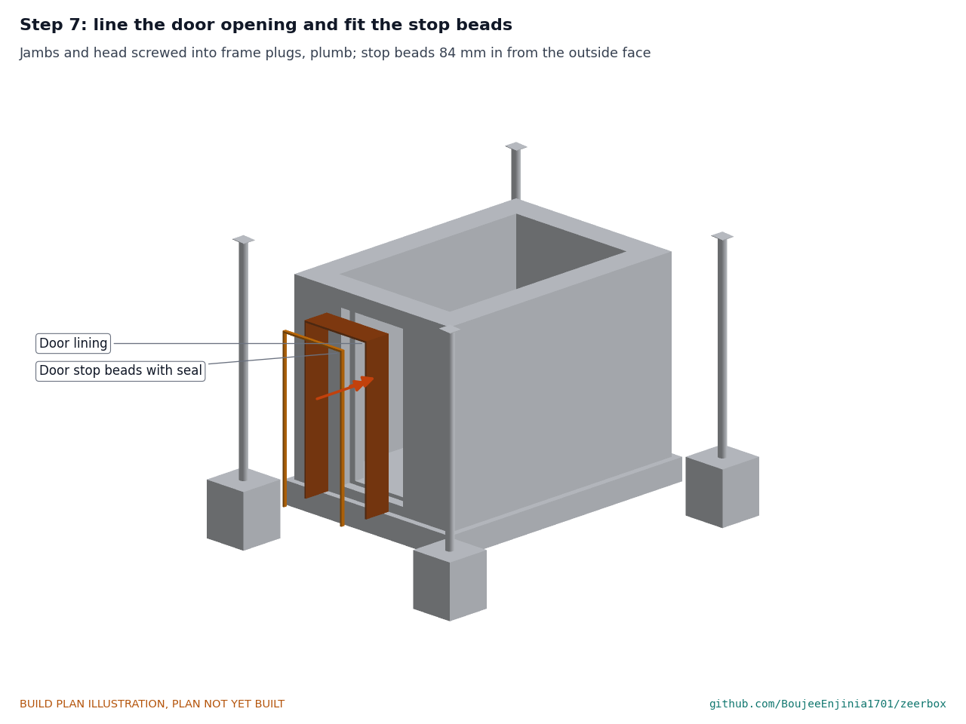
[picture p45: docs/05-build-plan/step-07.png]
Step 7


Jambs, then head, into frame plugs, plumb; stop beads 84 mm in from the outside face.

### Step 8: hang the door

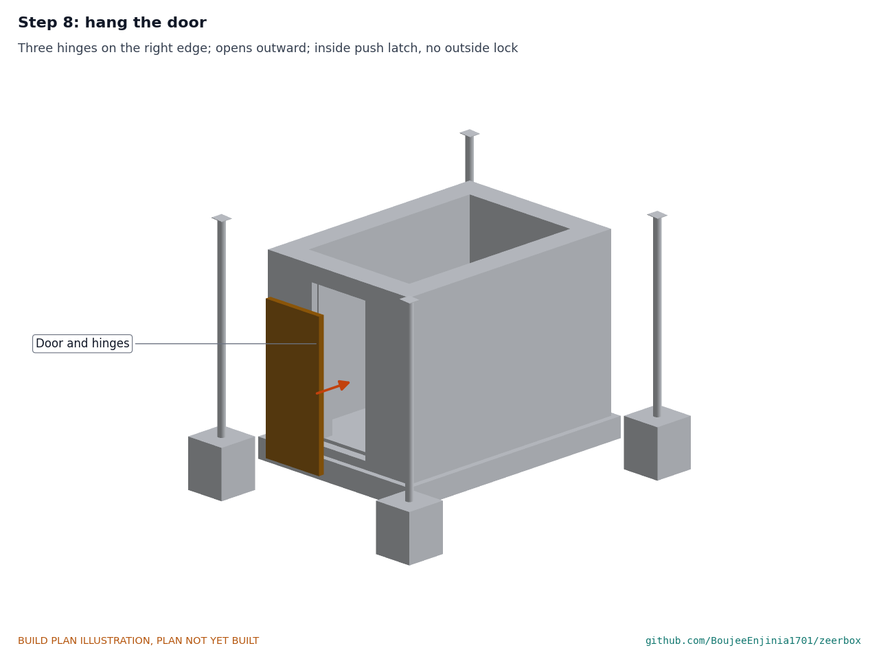
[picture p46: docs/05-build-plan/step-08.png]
Step 8


Three hinges on the right edge; the door opens outward. **Hold point:** the door opens from inside with one push before anyone works inside with it closed.

### Step 9: ceiling joists onto the wall tops

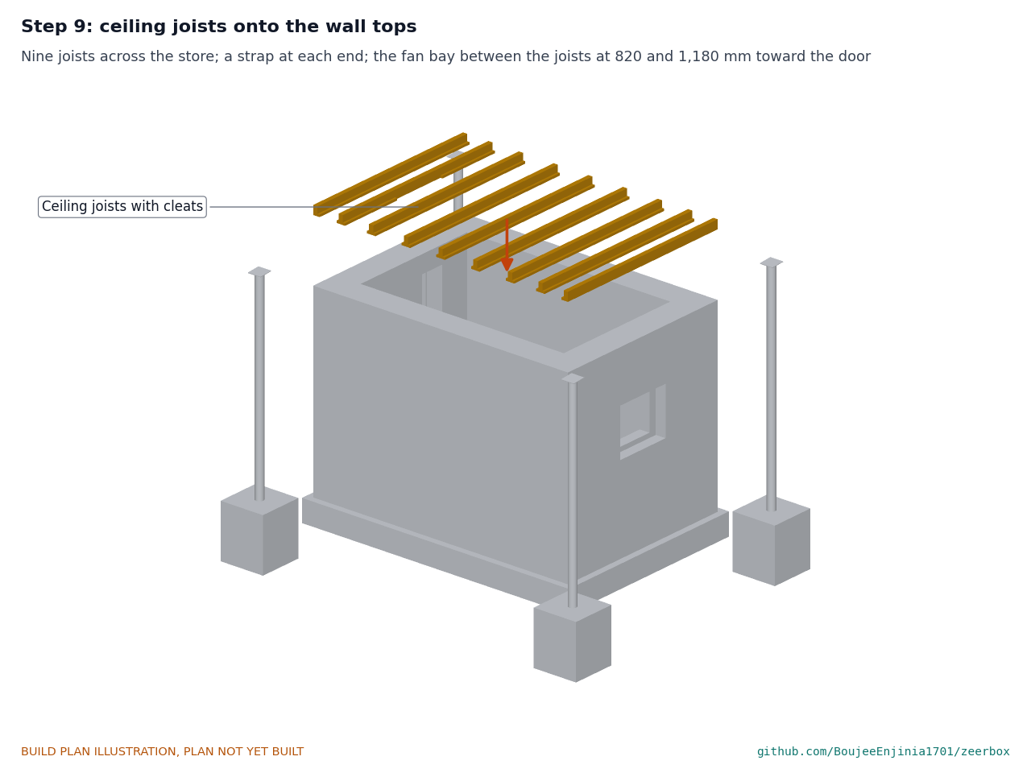
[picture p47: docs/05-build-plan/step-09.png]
Step 9


Nine joists across the store at their marks, each end nailed to its strap. The fan bay is between the joists at 820 and 1,180 mm toward the door.

### Step 10: vapor sheet and insulation into the bays

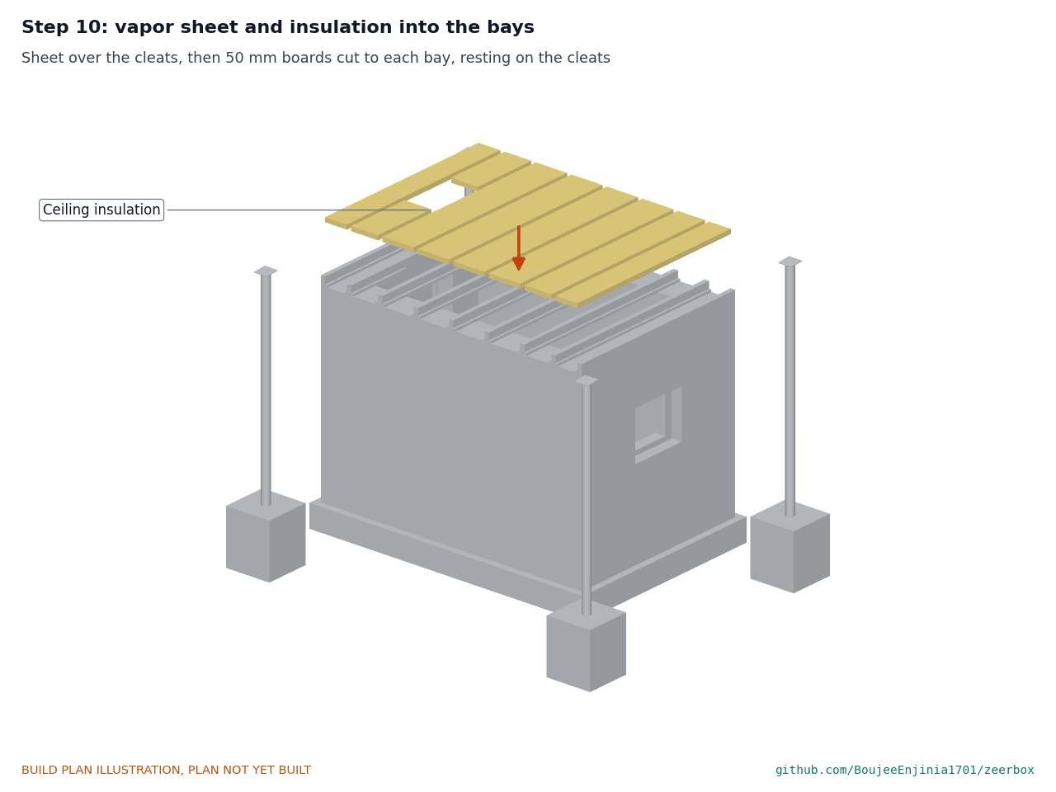
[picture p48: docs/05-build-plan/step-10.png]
Step 10


Sheet over the cleats, then insulation cut to each bay, resting on the cleats.

### Step 11: drop the fan box into the fan bay

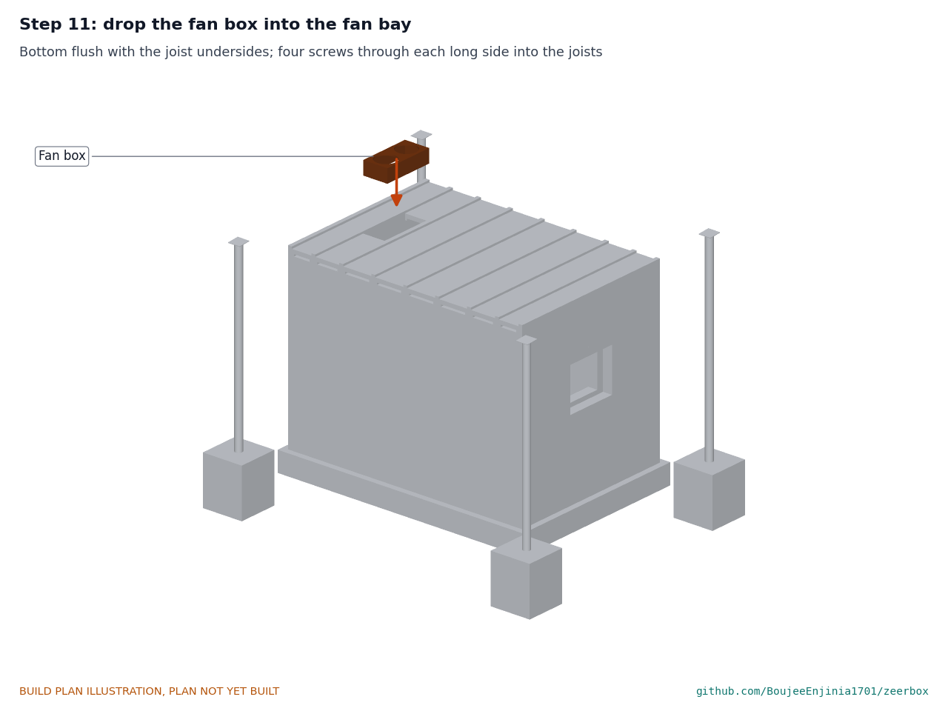
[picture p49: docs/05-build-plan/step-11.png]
Step 11


Bottom flush with the joist undersides; four screws through each long side into the joists.

### Step 12: nail the ceiling boards on

Step 12

Boards across the joists, cut round the fan box.

### Step 13: fans and shutters onto the fan box

Step 13

Each fan over its hole, blowing upward, four screws; a guard under each hole; a gravity shutter on top of each fan.

### Step 14: roof beams onto the post cap plates

Step 14

Two M10 coach screws up through each cap plate. Work from scaffold or a stable platform, never from the ceiling boards.

### Step 15: purlins onto the beams

Step 15

Five purlins at the marks, 700 mm apart; a hurricane tie at every crossing.

### Step 16: roof sheets onto the purlins

Step 16

Sheets laid down the slope with side laps facing away from the prevailing wind; a sealing-washer screw through every second crest at each purlin. **Hold point:** every sheet screwed down before work stops for the day.

### Step 17: panel frames onto the roof

Step 17

Base rails screwed through sheet crests into the purlins; legs and top rails bolted on.

### Step 18: solar panel onto its frames

Step 18

With a helper, lift the panel on and bolt it to the top rails through its frame holes. Check the tilt is 15° with an angle finder. Keep the panel leads apart and taped until step 25.

### Step 19: line the pad opening

Step 19

Four boards into frame plugs, flush with the outside face; seal outside.

### Step 20: pad frame onto the wall

Step 20

Battens plugged to the wall; sides screwed to them; top between the sides; bottom bars under the sides.

### Step 21: pad into its frame

Step 21

Slide the pad in from the front onto the bottom bars, steeper flutes sloping down toward the room, then fit the two front bars.

### Step 22: drip header through the frame

Step 22

Slide it in from the right through both side boards, holes facing down, open end 75 mm out on the right.

### Step 23: gutter under the pad

Step 23

Brackets plugged to the wall; gutter on the brackets, its top 20 mm below the pad, falling to the outlet.

### Step 24: sump drum and hoses

Step 24

Drum on level ground to the right of the pad, under the roof, lid on. Pump and float switch inside; feed hose from the pump to the header inlet; return hose from the gutter outlet to the lid.

### Step 25: power box, controller and sensor on the front wall

Step 25

Power box to the right of the door and the controller to its left, 1.0 to 1.3 m above ground, each on four screws in plugs. Drill a 22 mm hole in the top of the controller box, 70 mm from its middle toward the door, push the mode lamp body through from outside and tighten its nut inside, so the flange sits flat on top of the box. Screw the strip arm of the outside sensor to the wall about 1.35 m above ground, 75 mm above the top of the box, with its plates clear of the lamp by at least 15 mm. Wire as section 3.19.1 with the battery fuse out. **Hold point:** safety stops S3 and S4 of section 6.

### Step 26: racks in along the long walls

Step 26

Carry the rack parts in through the door and assemble each rack in place against a long wall, 100 mm from each end wall; bracket the end posts to the wall.

## 5. First checks

These are the checks a TRL 4 test report would record; this plan only lists them. Requirement numbers are those of ZBX-REQ-001.

*Table 2. First checks.*

| Check | Requirement | How | Pass when |
| --- | --- | --- | --- |
| Crate fit and reach | R1 | Load 24 empty crates; an adult reaches every crate from the aisle | 24 crates fit; no crate is lifted above 1.6 m |
| Door opens from inside | R9 | Close the door from inside; open it with one push, in the dark | Opens every time; no outside lock fitted |
| Pad wetting | R8 | Run the pump with the fans off for 10 minutes | The whole pad face is wet; no dry streaks; all water returns to the drum; no splash outside the gutter |
| Fan direction and shutters | R9 | Run the fans at full speed | Air leaves upward through both shutters; shutters close by themselves when the fans stop; guards fitted on both faces |
| Airflow | R2 | Vane anemometer over the pad face at nine points | About 0.5 m/s mean face velocity (about 560 m³/h, ZBX-CAL-001) |
| Cooling on a dry day | R2 | Log inside and outside temperature and humidity for a day with the store loaded | Store air 8 K or more below outside air at about 35 °C and 30 % RH |
| Store humidity | R3 | Same log | 80 % RH or more while cooling |
| Mode change | R4, R5 | Feed the controller a humid-air reading and a 95 % RH store reading from a test input | It switches to hold, and stops the pump after 60 minutes at 95 %; the lamp shows the mode |
| Charge controller and fuse | R7, R9 | Measure the charge voltage; check the fuse rating and the BMS charge limit on their labels | Charge voltage within the battery maker's limit; 15 A fuse at the terminal; BMS 10 A or more |
| Day's energy | R7 | Log battery voltage over a sunny design day | The battery ends the day fuller than it started |
| Water use | R8 | Mark the drum level morning and evening | 70 L a day or less (about 36 L expected) |
| Roof tie-down | R11 | Pull up on each purlin end by hand; look at every tie and screw | Nothing lifts; every tie, coach screw and sheet screw in place |

## 6. Safety stops

Stop at each point. Carry on only when everything listed is true.

- **S1. Before digging.** The site has been checked for buried cables and pipes; the trench and holes are fenced or covered when left.
- **S2. Before work at height (steps 9 to 18).** Work from scaffold or a stable platform with a second person present; never stand on the ceiling boards or the roof sheets; no work in wind strong enough to lift a sheet.
- **S3. Before the battery fuse goes in.** All wiring done and labelled; with the fuse out, no circuit reads short; panel leads connected to the charge controller only after the battery, as the controller maker says; battery shaded and ventilated in its box.
- **S4. Before the battery is charged unattended.** One full day of attended charging: battery temperature checked hourly, never charged below 0 °C or above 45 °C.
- **S5. Before the fans are run.** Guards fitted on both faces of both fans; nobody's hands near the fan box.
- **S6. Before the pump is run.** Drum covered; the float switch stops the pump when the drum is low; every cable joint near water is IP65 with a drip loop.
- **S7. Before anyone works inside with the door closed.** The door opens from inside with one push; the store has been aired out if the fans were off.
- **S8. Before produce goes in (outside this plan).** The drum has been drained and cleaned and the weekly cleaning routine is agreed with the users; the store is not used for meat, fish, milk or medicines.

## 7. Tools, skills and workspace

**Tools.** Tape measure, builder's line and pegs, spirit level and water level, builder's square; spade, mattock and wheelbarrow; concrete mixing tools and a tamping rod; bricklaying trowel, jointer and line blocks; hand saw and circular saw; drill with masonry, wood and metal bits up to 13 mm and a 250 mm hole saw or jigsaw; screwdrivers and spanners to 17 mm; hacksaw and files; tin snips and a folding bar for 0.5 mm sheet; an arc welder (or a workshop that welds) for the cap plates; angle finder; multimeter; vane anemometer and a temperature and humidity logger for the first checks; scaffold or a stable platform.

**Skills.** A competent mason for the footings, walls, lintels and capping course; a carpenter for the linings, door, ceiling, fan box, roof framing, pad frame and racks; welding of the four cap plates and anchor bars; basic 12 V wiring with crimped ferrules. All circuits are 12 V DC; no mains wiring is part of this build.

**Workspace.** A level, firm, well-drained site about 4.5 x 3.5 m with room around it to work and store bricks; shade and water for curing concrete and mortar; a covered, dry place to keep the rice husk, timber and electrical parts until they are fitted.

**Personal protective equipment.** Gloves for brick, concrete and sheet; eye protection for cutting and drilling; a welding mask and gloves for the cap plates; hearing protection for the circular saw; a dust mask for handling lime and husk; hard hats while the roof is being built.

## 8. Where the numbers come from

- Model and constructability checks: `cad/src/model.py` (`python cad/src/model.py --check`); STEP and STL exports in `cad/step/` and `cad/stl/`.
- Pictures: `cad/src/build_plan_media.py`, using `.kit/build_views.py`; written to `docs/05-build-plan/` and `cad/drawings/ZBX-DWG-101` to `ZBX-DWG-118`.
- General arrangement: `cad/drawings/ZBX-DWG-001.pdf`, Rev P3.
- Calculations: `docs/04-calcs/01-sizing.md` (ZBX-CAL-001 v0.3) and `docs/04-calcs/sizing.py`; structure and roof framing in section 10 and Table 6a.
- Bill of materials: `bom/bom.csv`.
- Decisions: `docs/decisions/0003-design-for-construction.md` (ZBX-DDR-003), with ZBX-DDR-001 and ZBX-DDR-002; open items in `docs/06-design-decisions.md` (ZBX-DEC-001).
- Requirements: `docs/03-requirements.md` (ZBX-REQ-001 v0.5).

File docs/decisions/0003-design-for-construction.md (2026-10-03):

---
doc_id: ZBX-DDR-003
title: ZeerBox design for construction
project: ZeerBox
doc_type: Design decision record
version: "0.3"
status: Draft
date: '2026-10-02'
author: Amish Chadha
license: CERN-OHL-S-2.0
revisions:
- version: "0.1"
  date: '2026-10-02'
  author: Amish Chadha
  change: Changes that make the concept physically buildable, with the reason for each; made under Amish's 2026-09-30 instruction to make the design physically buildable; open for his review
- version: "0.2"
  date: '2026-10-02'
  author: Amish Chadha
  change: Accepted by Amish on 2026-10-02, with A1 and A2 decided as option (a)
- version: "0.3"
  date: '2026-10-02'
  author: Amish Chadha
  change: Controller mode lamp and plate shield for the outside sensor added to the model (C11 and C12); appearance model brought into line
---

# 0003: Design for construction

- **Date:** 2026-10-02
- **Status:** Draft; accepted. Amish, 2026-10-02: "APPROVED: The open decisions from the last wave (TremorTrace to ZeerBox) came in after the review and aren't on the page either." This approves the recommendation written for each open decision in the design decisions register (ZBX-DEC-001 v0.1): every change in Table 1 is accepted as made, and A1 and A2 in Table 3 are decided as recorded there.

## Context

On 2026-09-30 Amish asked for every repo to get an illustrated prototype build plan and wrote: "If you are realising that the design cannot be built as per concept - fix the design assumptions to match and be physically feasible as you draw the illustrations." The TRL 3 model of ZBX-DDR-002 showed what ZeerBox does, and its calculations hold, but many of its parts were massing shapes: a roof sheet on four posts with nothing under it, a solid ceiling slab, openings cut through a cavity wall with no lintels or linings, fan holes that left 50 mm brick piers, shelves that the rack posts passed through, and a solar panel floating 150 mm above the roof.

Each component was reviewed for how it is made (cast, laid, sawn, bent, welded, bought) and how it joins the parts next to it. The model now builds every component with the faces it sits on (`cad/src/model.py`) and runs 7,816 constructability checks with build123d (`python cad/src/model.py --check`): no two components share volume except a post cast into its footing, 39 named joints touch, no piece floats, and seven clearances hold (fan shutters to the roof framing, the door in its lining, the air path above the top crates, and others). All pass.

The changes keep what ZeerBox does: the same 2.4 x 1.5 x 2.0 m room, double brick walls with a dry rice husk cavity, 150 mm pad on the back wall, two 250 mm exhaust fans at the door end, sump, controller, 150 W panel, battery, racks and 24 crates. The calculated store temperature, humidity, airflow, water and energy are unchanged (ZBX-CAL-001 v0.3). Nothing here changes the pitch or the safety case.

## Decision

*Table 1. Changes made to the model, the BOM and the calculations.*

| # | Problem in the concept | Change made | Why this way |
| --- | --- | --- | --- |
| C1 | The two 250 mm fan holes in the front wall, 575 mm each side of the door axis, left about 50 mm of brick between each hole and the door opening and 50 mm to the inner corners: piers too narrow to lay or to carry a lintel. | Both fans sit in one plywood fan box (310 x 640 mm, 150 mm deep, 18 mm plywood) dropped into a joist bay of the ceiling, centred 1,000 mm from the store's centre toward the door, over the aisle. They blow up into the shaded 450 mm roof space through gravity shutters. | The fans still exhaust at the door end with the pad opposite, so the air still sweeps the aisle and crates. A ceiling bay needs no lintel and no brick cut, the shutters close by gravity when lying flat, and rain cannot reach them under the roof. The wall gains 0.1 m² and the heat load 1 W. See A1. |
| C2 | The roof sheet sat on the four post tops with nothing under it (a 3.9 x 3.0 m sheet cannot span between posts), and the posts ran into the sheet. | Two 75 x 150 mm beams across the store on the post lines, five 50 x 150 mm purlins along it at 700 mm, sheets screwed to the purlins. Each post is an 89 mm galvanized pipe with a 150 x 150 x 6 mm cap plate welded at the 4° roof slope and a 12 mm anchor bar through its foot; two M10 coach screws hold each beam; a hurricane tie holds each purlin crossing. | Purlins 100 mm deep would be over-stressed at 11.6 MPa under uplift; 150 mm deep gives 5.2 MPa (ZBX-CAL-001 Table 6a). The framing weight lowers the uplift per post from 2.23 to 1.94 kN, so the decided 500 mm footings now have a factor of 1.81. |
| C3 | The walls stood on bare ground; the calculation assumed a 450 mm strip footing that was neither modelled nor priced. | A concrete strip footing 450 mm wide and 250 mm deep, top at ground level, with a damp-proof strip on top under both leaves and the cavity (BOM line 15). | Matches the calculation's bearing check (16 kPa) and gives the husk fill its dry base. |
| C4 | Door and pad openings were cut straight through the cavity wall: no lintels, the husk fill open at every reveal, no door frame or hinges, and a 50 mm door leaf where the calculation's U value assumes 50 mm of insulation between two 12 mm skins. | One 115 x 100 mm hardwood lintel over each leaf at both openings (150 mm bearing). A 20 mm board lining on every reveal closes the cavity; the brick openings are 40 mm wider and taller to keep the clear sizes (door 800 x 1,800 mm, pad 600 x 500 mm). The door gets stop beads with a seal, three hinges, a 74 mm leaf, and opens outward with an inside push latch and no outside lock. | Lintels were already in BOM line 1; now they are drawn and priced. The linings keep the husk in and dry. An outward door keeps the racks and aisle clear and cannot be held shut by produce inside. |
| C5 | The ceiling was a solid 120 mm slab. | Nine 50 x 100 mm joists across the wall tops with 25 x 25 mm cleats, 50 mm insulation and a vapor sheet on the cleats, 20 mm boards nailed on top, a galvanized strap at each joist end. The wall top is a brick capping course over both leaves and the cavity. | The same 120 mm build-up and U value as the calculation; joist spacing (410 mm or less) leaves one 310 mm bay for the fan box. |
| C6 | The rack posts passed through the shelf boards, and the shelves had no rails. | Each rack: six 50 x 50 mm posts, six 50 x 75 mm rails screwed to the inside faces of the posts, 15 slats per shelf across the rails with gaps for air, two steel angle brackets tying the end posts to the wall. | The rail size is the one the calculation checked (0.58 MPa); slat gaps let the air pass up through the crates; the brackets stop a loaded rack tipping. |
| C7 | The pad frame was a ring with nothing to hold the pad in or the frame on the wall; the drip header floated 14 mm above the frame; the gutter had no brackets. | Frame of 25 mm boards on two wall battens, two bottom bars the pad stands on, two front retaining bars; the header lies on top of the pad through holes in the frame sides; the gutter sits on two strip brackets 20 mm below the pad. | Every piece is screwed or plugged to the one beside it; the pad slides out from the front for cleaning. |
| C8 | The solar panel floated 150 mm above the roof with no mount. | Two aluminium frames (angle base rail screwed through sheet crests into two purlins, two flat-bar legs, angle top rail bolted to the panel frame). The panel centre moves 50 mm down the slope and 100 mm higher so both base rails cross two purlins. Replaces the roof clamps of BOM line 10. | The panel keeps its 15° tilt and size; the fixing reaches the purlins, not just the thin sheet. |
| C9 | The sump drum stood half outside the roof edge, in the sun. | Moved 190 mm toward the store, fully under the roof; hoses routed from the pump to the header end and from the gutter outlet to the drum lid. | Keeps the recirculating water shaded (cooler water, slower bacterial growth). |
| C10 | The outside sensor's radiation shield floated 40 mm off the wall. | A short bent strip arm screws it to the wall. | A fixing. |
| C11 | The three-color mode lamp in the precis had no place in the model, and the controller box was a solid block. | The box is a hollow clear-lid IP65 box (80 x 200 x 250 mm, 3 mm wall) with a 22 mm hole in its top, 70 mm toward the door from the middle. The lamp (30 mm flange, 3 mm thick, 22 mm dome standing 20 mm above it) sits in the hole. Amish, 2026-10-02: decision 7. | A bought lamp is fitted in a drilled hole, so the hole and the flange have to be in the model; the 100 mm clearance to the door lining and 15 mm to the sensor shield are checked. |
| C12 | The outside sensor's shield was a 40 x 40 x 60 mm block. | Six round plates 46 mm across and 2 mm thick at a 10 mm pitch, on a 6 mm stud, on the strip arm (lowest plate 1,320 mm above ground, centre 63 mm from the wall). Amish, 2026-10-02: decision 8. | Stacked plates shed rain and let air through, as a real radiation shield does; the footprint grows by 3 mm a side. |

*Table 2. Knock-on changes.*

| Item | Change | Reason |
| --- | --- | --- |
| Calculations | ZBX-CAL-001 v0.3: heat load 442 to 443 W; bricks 1,977 to 1,973; husk 1.3 to 1.2 m³; uplift per post 2.23 to 1.94 kN, footing factor 1.58 to 1.81; roof and ceiling members checked. Temperature, humidity, airflow, water and energy unchanged. | Follows the model. |
| Cost | Value-engineering target: USD 300 for the kit (`budget_usd`, unchanged). Estimated cost of the constructable design: kit USD 299 (USD 1 under the target); structure USD 574, costed separately (was USD 355); store USD 873. | New BOM lines 15 to 18; lines 1, 3, 4, 6, 10 and 12 repriced. |
| BOM | Lines 15 (strip footing), 16 (door lining, stops, fan box), 17 (roof beams and purlins), 18 (panel frames) added; lines 1, 3, 4, 5, 6, 8, 10, 12 respecified. | Parts added for construction. |
| Drawings | ZBX-DWG-001 Rev P3; making sketches ZBX-DWG-101 to 118 added. | Follows the model. |
| Documents | ZBX-REQ-001 v0.5 and ZBX-PRC-001 v0.5 updated for the ceiling fans, cost and structure figures. No requirement changed status except R12, now reported against the value-engineering target. | Follows the model. |

*Table 3. Decided by Amish, 2026-10-02.*

| # | Question | Options | Recommendation |
| --- | --- | --- | --- |
| A1 | Fan position. The concept put the fans in the front wall beside the door, which leaves piers too narrow to build. | (a) ceiling fan box at the door end, as modelled; (b) keep wall fans by raising the room about 250 mm so they fit above the door (more brick, a taller room, a new heat balance); (c) narrow the door to about 600 mm to widen the piers. | (a): no change to the room, the airflow or the door. **Decided by Amish, 2026-10-02: (a).** |
| A2 | Moist exhaust air now leaves into the roof space, about 2.5 m from the pad intake. | (a) accept, and check at TRL 4 that it does not drift back to the pad; (b) add a short duct to carry it out past the roof edge at the door end. | (a); the roof space is open on all four sides. **Decided by Amish, 2026-10-02: (a), with (b) only if the TRL 4 check shows moist air drifting back to the pad.** |

## Consequences

- `design_state: constructable` in `project.yaml`. The build plan ZBX-BLD-001 shows every component and step in pictures generated from the model (`cad/src/build_plan_media.py`); open questions are in the design decisions register ZBX-DEC-001.
- Requirement status: 7 met (3 by design or logic review), R12 USD 1 under its value-engineering target, 1 at risk (R3), none not met, 3 not verifiable at TRL 3 (ZBX-CAL-001 v0.3).
- The appearance model `cad/src/product_model.py` now takes its structure, cooling kit and controller from the constructable model, and the render scenes are exported. The photoreal renders (`media/render-*.png`), `media/card.png` and `media/social-preview.png` are made on Amish's Mac next. The concept media in `media/` are regenerated from the constructable model.
- The concept views (hero, exploded, cutaway, blueprint) leave out the below-ground footings; the general arrangement and the build plan show them.

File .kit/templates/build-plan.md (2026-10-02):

---
doc_id: PRJ-BLD-001
title: Project prototype build plan
project: Project name
doc_type: Build plan
version: "0.1"
status: Draft
date: YYYY-MM-DD
author: Amish Chadha
license: CERN-OHL-S-2.0
revisions:
  - version: "0.1"
    date: YYYY-MM-DD
    author: Amish Chadha
    change: First build plan; design made constructable
---

# Project prototype build plan

**Plan, not yet built.** How to build the first proof-of-concept prototype, component by component. Building and testing to it is TRL 4 work. Decisions still to be made are kept in the design decisions register (`docs/06-design-decisions.md`), not here.

## 1. What you are building

Every component, pulled apart and numbered in build order

One short paragraph: what the prototype is, how many components, which are made and which are bought, and the main ways they are made.

## 2. What changed to make it buildable

| Component | The concept had | The buildable design has | Why |
| --- | --- | --- | --- |

## 3. Making the components

### 3.1 Component name

Making sketch

**What it is and what it is made from.**

**How to make it.**

1. Mark out ...
2. Cut ...

**How it fits the parts next to it.**

Close-up of the joint

**Check before moving on.**

## 4. Putting it together

### Step 1: ...

Step 1

## 5. First checks

| Check | Requirement | How | Pass when |
| --- | --- | --- | --- |

## 6. Safety stops

## 7. Tools, skills and workspace

## 8. Where the numbers come from

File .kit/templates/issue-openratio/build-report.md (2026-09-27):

---
name: Build report
about: Tell us what happened when you built, printed or tested part of this design
title: "Build report: "
labels: build-report
---

This is a research and educational prototype, not a medical device. It is a TRL 3 concept and is not released for fabrication. If you build any part of it, you do so at your own risk. Reports help everyone.

**What you built** (part, sub-assembly or test)

**Materials, tools and settings**

**What worked**

**What did not work, with photos or measurements if you have them**

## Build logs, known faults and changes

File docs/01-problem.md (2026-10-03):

---
doc_id: ZBX-PRB-001
title: ZeerBox problem statement
project: ZeerBox
doc_type: Problem statement
version: "0.7"
status: Draft
date: '2026-10-02'
author: Amish Chadha
license: CERN-OHL-S-2.0
revisions:
- version: "0.1"
  date: '2026-09-24'
  author: Amish Chadha
  change: Initial scaffold
- version: "0.2"
  date: '2026-09-25'
  author: Amish Chadha
  change: Populate to TRL 2 (users, context, constraints, out of scope, prior work with sources)
- version: "0.3"
  date: '2026-09-25'
  author: Amish Chadha
  change: Record the budget decision (ZBX-DDR-001 item 1), the co-design partner rule and the TRL 3 water figure
- version: "0.4"
  date: '2026-09-25'
  author: Amish Chadha
  change: Recommendations accepted by Amish (DDR-002). Dry rice husk fill in place of the wet-cavity wall; cost and water figures from ZBX-CAL-001 v0.2
- version: "0.5"
  date: '2026-09-26'
  author: Amish Chadha
  change: Stronger sources
- version: "0.6"
  date: '2026-10-02'
  author: Amish Chadha
  change: Cost constraint restated against the value-engineering target with the constructable design's figures (ZBX-DDR-003)
- version: "0.7"
  date: '2026-10-02'
  author: Amish Chadha
  change: Partner, region and crop mix answered by Amish's decision of 2026-10-02 (ZBX-DEC-001)
---

# ZeerBox problem statement

Smallholder farmers and traders in hot, dry regions lose a large share of their tomatoes, leafy greens and other perishables in the days after harvest because they have nowhere cool to keep them, and refrigerated cold rooms cost tens of thousands of dollars and need reliable power. Passive evaporative coolers are cheap and proven but small, hard to load, and weak whenever the air turns humid. Design with, not for: requirements must come from co-design sessions and field trials with the intended users through a local partner.

## The problem

Around 14 % of the world's food is lost between harvest and retail, and losses are higher for fruits and vegetables than for cereals at every stage of the chain ([FAO, *The State of Food and Agriculture 2019*](https://www.fao.org/interactive/state-of-food-agriculture/2019/en/)). In sub-Saharan Africa, on-farm losses of fruits and vegetables reported in that work range from 0 to 50 % ([summary of FAO SOFA 2019](https://www.globalagriculture.org/news/fao-14-of-the-worlds-food-is-lost-between-harvest-and-retail/)), and FAO's earlier estimate put total food loss in the region at about 37 % of production ([World Bank, *Africa Myths and Facts*](https://www.worldbank.org/en/programs/africa-myths-and-facts/publication/is-post-harvest-loss-significant-in-sub-saharan-africa)). Heat is the main driver for perishables: a tomato held at 30 to 35 °C respires and loses water several times faster than one held near its recommended 12.5 to 15 °C and 90 to 95 % relative humidity (RH) ([UC Davis Postharvest Center, tomato fact sheet](https://postharvest.ucdavis.edu/produce-facts-sheets/tomato)).

The result is that a farmer must sell on the day of harvest, often to the first trader who arrives, at whatever price is offered. Stored produce that would fetch a better price three or four days later spoils first.

Three gaps block the obvious fix:

1. **Refrigeration is out of reach.** A solar-powered walk-in cold room for smallholder agriculture in Malawi and Zimbabwe cost about $40,000 per unit for 10 t of capacity, with a 10 kWp array and 15 kWh of batteries, and some pilot rooms stood largely unused ([Efficiency for Access, lessons from Zimbabwe and Malawi](https://efficiencyforaccess.org/wp-content/uploads/Lessons-learned-from-implementing-solar-powered-walk-in-cold-rooms-for-smallholder-agriculture-in-Zimbabwe-and-Mal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)). Pay-per-crate solar walk-in cold rooms such as ColdHubs in Nigeria, at about $0.50 per crate per day, work where a business runs them, but they sit in markets, collection centers and farm clusters rather than on individual farms ([ColdHubs](https://coldhubs.com/); [IFPRI](https://www.ifpri.org/blog/coldhubs-addressing-crucial-problem-food-loss-nigeria-solar-powered-refrigeration/)).
2. **Passive evaporative coolers are small and slow.** Clay pot-in-pot coolers and brick zero energy cool chambers (ZECCs) cost little and roughly double the shelf life of tomatoes in the dry season, but they hold tens of kilograms, sit at ground level where every crate must be lifted in and out, and depend on wind for air movement ([MIT D-Lab evaluation in Mali](https://news.mit.edu/2018/mit-d-lab-cite-evaluation-low-cost-evaporative-cooling-devices-mali-0620); [ZECC storage study, *e-planet* 18(2)](https://www.e-planet.co.in/images/Publication/vol-18-2/storage.pdf)).
3. **Evaporative cooling fails in humid weather, and nobody tells the user.** Higher humidity slows evaporation and so reduces the cooling effect: in the Mali field evaluation, brick chambers cut the daily peak temperature by up to 10.4 °C when the air was below 40 % RH but by only 4.2 °C above 70 % RH ([Verploegen, Sanogo and Chagomoka, MIT D-Lab](https://d-lab.mit.edu/sites/default/files/inline-files/GHTC%20-%20Evaluation%20of%20Low-Cost%20Evaporative%20Cooling%20Technologies%20for%20Improved%20Vegetable%20St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)). In the rainy season a wet pad adds humidity without much cooling, and a sealed, damp chamber can grow mold. Passive designs cannot sense this or change their behavior.

ZeerBox is a walk-in evaporative store, large enough for about 24 crates, that uses a small solar-powered fan to pull outside air through a wetted pad and a controller that reads temperature and humidity inside and out, so it cools hard when the air is dry, ventilates at night when the air is humid, and tells the user which mode it is in.

## Users and context

| User | Need | Context |
| --- | --- | --- |
| Smallholder vegetable grower | Hold one to five days of harvest so produce can be sold when the price is right, not on the day it is picked | 0.5 to 2 ha of tomatoes, peppers, okra, leafy greens; sells at a farm gate or weekly market |
| Farmer group or cooperative | Shared store near the collection point for several members' crates | Rota for loading, watering and cleaning; simple record of whose crates are where |
| Market trader | Keep stock fresh between market days | Stall or small depot near a market, several deliveries a week |
| Local builder (mason, carpenter) | Build the walls, roof and door from local materials with familiar methods | Brick or block walls, timber, corrugated sheet; no specialist cooling trades |
| Local electrician or phone-repair technician | Install and repair the fans, pump, solar and controller | 12 V solar home system skills; hand tools and a multimeter |

### Operating environment

- **Climate (design case):** hot, dry season in the Sahel and similar semi-arid regions, daytime highs of 32 to 40 °C and 15 to 35 % RH. The design point is 35 °C and 30 % RH.
- **Climate (off-design):** rainy season, 25 to 32 °C and 60 to 90 % RH, when evaporative cooling gives little benefit.
- **Water:** a borehole, well, tap or rainwater tank within carrying distance; water may be hard or silty.
- **Power:** no grid, or unreliable grid. About 5 peak sun hours per day in the dry season.
- **Produce:** mixed perishables in 20 kg plastic or wooden crates, loaded daily, often warm from the field.
- **Site:** open ground near the farm or market, dust, termites, livestock, occasional strong wind.
- **Supply chain:** bricks, sand, cement, timber and corrugated sheet are available locally; 12 V solar parts, DC fans and small pumps are sold in regional towns; cellulose cooling pads are sold for poultry houses and greenhouses but may need to come from a regional city.

## Constraints

- The $300 USD budget (`project.yaml`) covers the cooling equipment kit: pad, sump and pump, fans, controller, solar panel, power box and wiring. The walk-in structure is built from local materials and costed separately (decided by Amish, 2026-09-25, ZBX-DDR-001 item 1). The USD 300 is a hypothetical value-engineering target, not a limit (Amish, 2026-10-01). Estimated cost of the constructable design: USD 299 for the kit (USD 1 under the target) and about USD 574 for the structure (ZBX-CAL-001 v0.3).
- Structure built by a local mason and carpenter from local materials, with no specialist refrigeration skills, refrigerant or mains power.
- Fans, pump and controller run from one small solar panel at 12 V, safe to touch and to work on.
- Water use modest enough to carry or pump by hand on the hottest day.
- No refrigerant, no compressor and no claim of cold-chain temperatures. ZeerBox slows spoilage; it does not replace a refrigerator.
- Every electrical and water part replaceable with a generic part from a regional town.

## Out of scope

- Refrigerated cold storage below about 15 °C (see ColdPod in this portfolio for active refrigeration).
- Storage of meat, fish, milk or vaccines, which need true cold chain.
- Drying, curing or processing of produce.
- Grain storage (see GrainGuard).
- Market linkage, pricing or the business model for a shared store, which a partner must design with users.

## Prior work

- **Pot-in-pot cooler (zeer).** Mohammed Bah Abba popularized the clay pot-in-pot cooler in Nigeria from 1995 ([MIT D-Lab, Mali evaluation](https://d-lab.mit.edu/sites/default/files/inline-files/GHTC%20-%20Evaluation%20of%20Low-Cost%20Evaporative%20Cooling%20Technologies%20for%20Improved%20Vegetable%20St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)) and received a Rolex Award for Enterprise; *TIME* reported eggplants keeping for 27 days instead of three and 12,000 coolers sold ([*TIME*, Best Inventions of 2001](https://content.time.com/time/specials/packages/article/0,28804,1936165_1936254_1936632,00.html)). ZeerBox takes its name and its principle from the zeer.
- **Zero energy cool chamber (ZECC).** A double brick wall with a wet sand cavity, developed at the Indian Agricultural Research Institute from 1986. One study measured 4.4 to 5.0 K below ambient on monthly averages and 7.25 K on the best day, with tomato shelf life rising from 6 to 11 days and banana from 7 to 20 days ([*e-planet* 18(2)](https://www.e-planet.co.in/images/Publication/vol-18-2/storage.pdf)). ZeerBox borrowed the wet-cavity wall at TRL 2; the TRL 3 heat balance found little benefit with forced air, so the cavity is now filled with dry rice husk (ZBX-DDR-002 item 12).
- **MIT D-Lab evaluation in Mali.** Brick chambers and clay pot coolers achieved more than 8 °C of cooling in real use in the dry season, and brick chambers outperformed straw and sack designs ([Verploegen, Sanogo and Chagomoka, MIT D-Lab](https://d-lab.mit.edu/sites/default/files/inline-files/GHTC%20-%20Evaluation%20of%20Low-Cost%20Evaporative%20Cooling%20Technologies%20for%20Improved%20Vegetable%20St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); [MIT News, 2018](https://news.mit.edu/2018/mit-d-lab-cite-evaluation-low-cost-evaporative-cooling-devices-mali-0620)). D-Lab has since piloted forced-air evaporative chambers in Kenya, some solar powered ([MIT D-Lab, evaporative cooling research](https://d-lab.mit.edu/research/evaporative-cooling-vegetable-preservation)). This is the closest prior work to ZeerBox and should be studied before TRL 3.
- **Fan and pad cooling in poultry houses and greenhouses.** Cellulose pad walls with exhaust fans are standard practice and well characterized; once the pad is fully wetted, extra water flow adds little ([review of evaporative pad operation, *Renewable and Sustainable Energy Reviews*](https://www.sciencedirect.com/science/article/pii/S1364032121009072)). ZeerBox scales this down to one small pad and two 12 V fans.
- **Solar cold rooms.** ColdHubs (Nigeria) and the Zimbabwe and Malawi pilots show both the demand and the cost and utilization risks of refrigerated storage for smallholders (sources above).

## Open questions

- Which partner organization and which region first? A dry-season vegetable area in the Sahel (Mali, Niger, northern Nigeria, Burkina Faso) or a semi-arid area of East Africa (northern Kenya) fits the design point. Decided by Amish, 2026-10-02 (ZBX-DEC-001): a group that has already field-tested evaporative cooling chambers with vegetable growers; the first candidate to approach is MIT D-Lab's evaporative cooling team, with a dry-season vegetable area of Mali as the first candidate region and tomatoes, peppers and okra as the crop mix, leafy greens on a separate rack; not yet approached.
- Is the store for one farm or for a group? This drives size, cost and who waters and cleans it.
- How far is the water source, and is about 36 L on a hot day acceptable (ZBX-CAL-001 v0.2)?
- Which crops dominate, and which must be kept apart (for example ethylene-producing tomatoes and bananas next to leafy greens)?
- Do users need the store to work in the rainy season, or only in the dry season when losses and prices are highest?

## User research and co-design

This design is for communities the author is not part of, so requirements come from the people who will use it.

- [ ] Identify a local partner organization (Helpful Engineering network, NGO, university or an existing evaporative cooling program)
- [ ] Run co-design sessions with intended users; record who, where and what was learned
- [ ] Validate climate, water, crop, load and cost assumptions in the field
- [ ] Revise requirements (REQ) from findings before freezing the design

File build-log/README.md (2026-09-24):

# Build log

Dated entries, newest first.

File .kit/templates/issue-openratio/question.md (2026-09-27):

---
name: Question
about: Ask about the design, the documents or the files
title: "Question: "
labels: question
---

**What are you looking at?** (file, drawing or section)

**Your question**

**Anything you have already tried or read**

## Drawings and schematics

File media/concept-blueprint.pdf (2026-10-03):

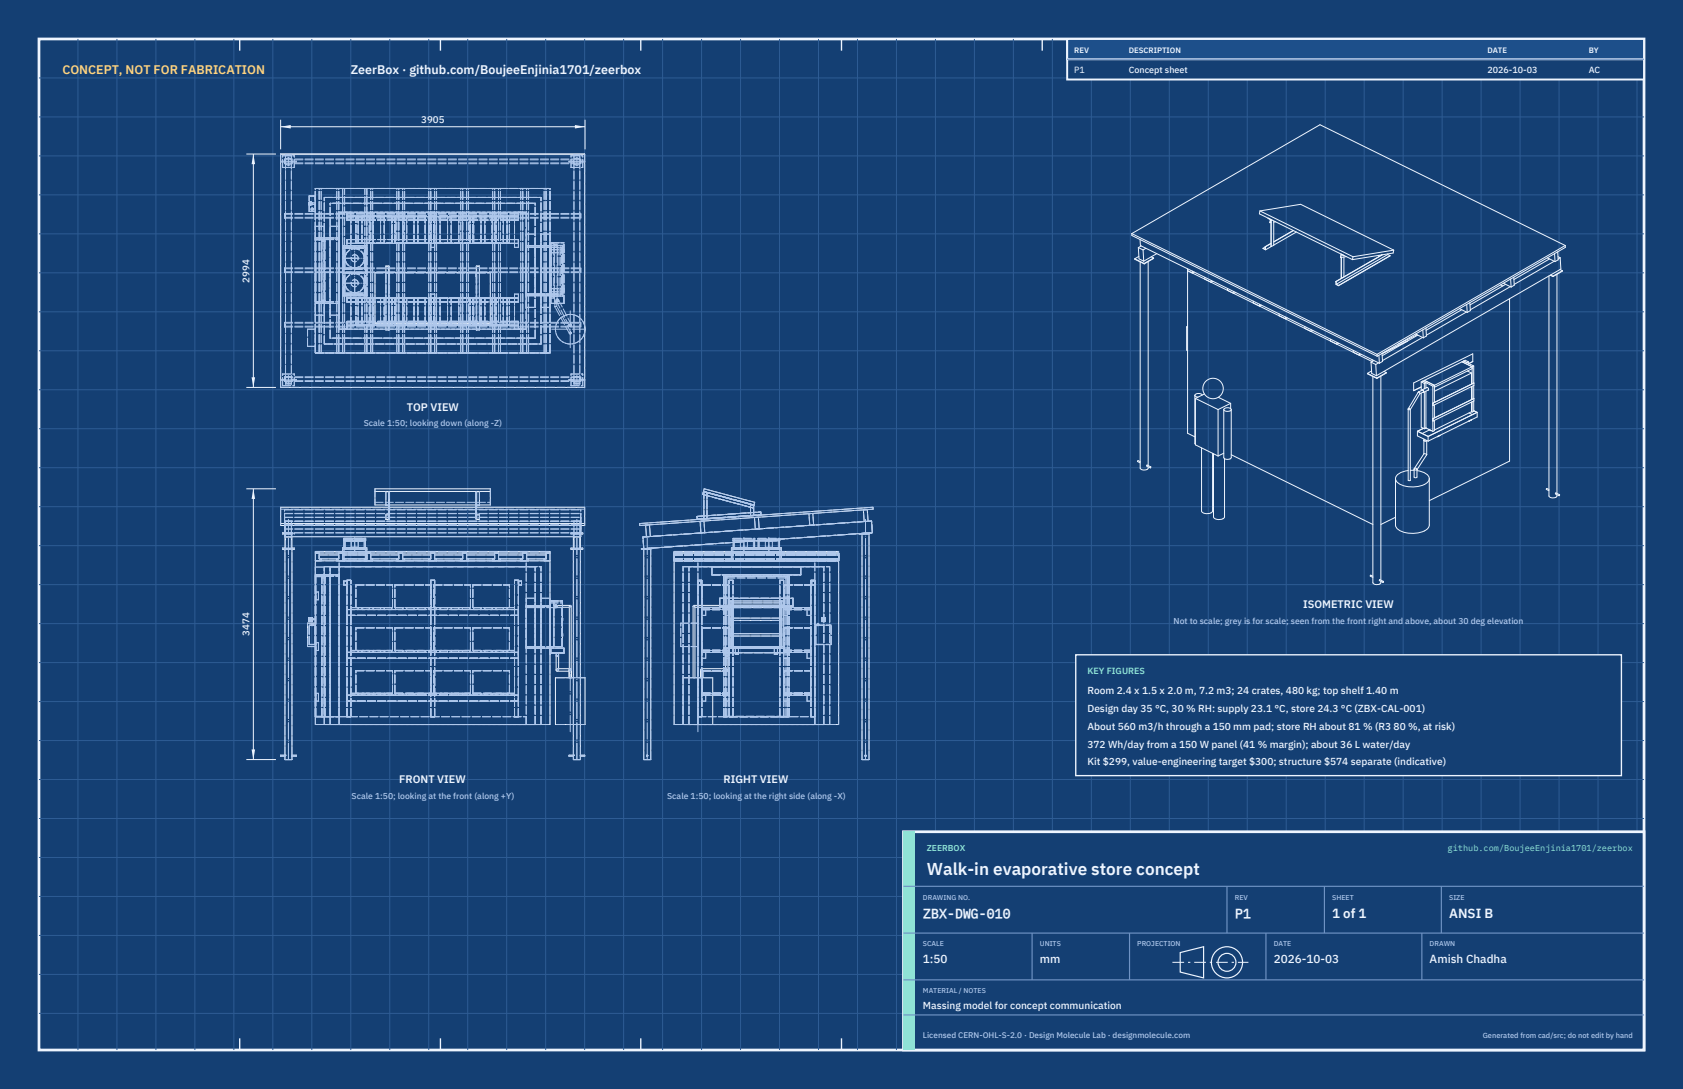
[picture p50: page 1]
CONCEPT, NOT FOR FABRICATION; ZeerBox · github.com/BoujeeEnjinia1701/zeerbox; FRONT VIEW; TOP VIEW; RIGHT VIEW; ISOMETRIC VIEW; REV; DESCRIPTION; DATE; Concept sheet; ZEERBOX; github.com/BoujeeEnjinia1701/zeerbox; DRAWING NO. ZBX-DWG-010; REV P1; SHEET 1 of 1; SIZE ANSI B; SCALE 1:50; UNITS mm; PROJECTION; DRAWN Amish Chadha; Licensed CERN-OHL-S-2.0 · Design Molecule Lab · designmolecule.com; Generated from cad/src; do not edit by hand

Scale 1:50; looking down (along -Z)

Not to scale; grey is for scale; seen from the front right and above, about 30 deg elevation

KEY FIGURES
Room 2.4 x 1.5 x 2.0 m, 7.2 m3; 24 crates, 480 kg; top shelf 1.40 m
Design day 35 °C, 30 % RH: supply 23.1 °C, store 24.3 °C (ZBX-CAL-001)
About 560 m3/h through a 150 mm pad; store RH about 81 % (R3 80 %, at risk)
372 Wh/day from a 150 W panel (41 % margin); about 36 L water/day
Kit $299, value-engineering target $300; structure $574 separate (indicative)

Scale 1:50; looking at the front (along +Y)

Scale 1:50; looking at the right side (along -X)

Walk-in evaporative store concept

MATERIAL / NOTES
Massing model for concept communication

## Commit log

2026-09-24 Initial scaffold: standard open hardware layout, CERN-OHL-S v2 + MIT licenses
    Claude-Session: https://claude.ai/code/session_01XuhhSU4W6fYhgCfURbrkut
    [bom.csv]
2026-09-25 Adopt portfolio kit v1.3.0: session commands, scale figure, 3D viewer, flow diagrams
    Adds .claude/commands (/populate, /advance-trl3, /rein-in, /refresh-media)
    so every Claude Code session starts from the standard prompts, and extends
    concept media with a 1.75 m scale figure, an interactive glTF viewer and
    system or energy flow diagrams. TRL cap 3 unchanged.
    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
2026-09-25 Kit v1.3.1: renderer fixes from the TremorTrace pilot
    Context scale parts for small objects, cutaway exclusions, and text
    labels in flow diagrams.
    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
2026-09-25 Populate zeerbox to a strong TRL 2 with concept media (overnight batches 4 and 5)
    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
    [bom.csv]
2026-09-25 Advance zeerbox to TRL 3 (batches 5 and 6)
    Decisions approved by Amish 2026-09-25 recorded in DDR-001. TRL 4 is on hold.
    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
    [bom.csv, results.csv, zeerbox-assembly.step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]
2026-09-26 Accept all recommendations (DDR-002), switch footer to designmolecule.com, add README write-up with new inspiration point
    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
    [bom.csv, results.csv, zeerbox-assembly.step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]
2026-09-27 Product appearance model and photoreal renders
    Adds cad/src/product_model.py (appearance model for renders only, all main
    dimensions from model.py) and Blender renders in media/render-*.png,
    captioned with the project, repository and viewing direction. README leads
    with the product render; trl stays 3.
    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
2026-10-01 Image quality pass: legible exploded views, flow diagrams and drawing sheets
    Kit 1.6.1 image layout: the parts list sits in its own column, number bubbles sit on visible parts and never overlap, small parts get a leader, pictures are cropped to the subject, flow labels keep numbers with their units, and sheet captions and the revision table no longer overprint. Concept images, blueprint and general arrangement sheet regenerated; repo-specific labels moved clear of other text and lines.
2026-10-02 Kit 1.7.0: constructable design, illustrated build plan and design decisions register
    The design is now constructable: every part can be made and fits its neighbours, with each change recorded in a Design for construction decision record (made under Amish's 2026-09-30 instruction; ope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
    FlexHand also credits Dr. Geeti Chadha as a contribut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
    [bom.csv, results.csv, zeerbox-assembly.step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]
2026-10-03 Carry approved follow-ups into the design and redo photoreal renders
    Amish approved the follow-up actions from the open-decision sign-off ("APPROVED CHANGES, COMPLETE THESE", 2026-10-02), the design-for-construction change tables in ten repos, the last wave's open dec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
    [bom.csv, zeerbox-assembly.step, zeerbox-assembly.stl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]
2026-10-28 Kit 1.9.1 upgrade: pipeline documents and detailed CAD for every option
    Kit 1.9.1 installed (.kit, CLAUDE.md, .claude/commands). Kit 1.8 pipeline: STEM check with fixes under the 2026-10-23 standing instruction, concept options with the current design as option A, URS, PRS, generated RTM, REG, FEA, RSK with design FMEA, MKT, PLN and DDR; kit 1.9 D3 model of every option passing cad/fidelity.json; independent review recorded in the STEM check. Amish's 2026-10-25 decisions recorded where he approved a recommendation; all others proposed, awaiting Amish. Product renders and the options picture follow in a later commit where not yet included.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
2026-10-29 Add the concept options picture rendered from the D3 option models
    media/options.png from Blender Cycles panels of every option, rendered on Amish's Mac; the label reads CURRENT DESIGN unless project.yaml records Amish's choice. Clears the docs check, which needs th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

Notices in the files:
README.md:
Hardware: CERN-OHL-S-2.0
